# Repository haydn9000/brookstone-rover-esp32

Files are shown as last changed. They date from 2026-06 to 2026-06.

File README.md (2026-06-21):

# Brookstone Rover, ESP32 Conversion

Firmware that converts a Brookstone Rover spy tank (tracked chassis, two DC
motors) into a Bluetooth-gamepad-controlled robot. The original WiFi board is
removed and replaced with an **ESP32 DevKit V1** driving a **DRV8833** dual
H-bridge, with a **BLE gamepad** (PS4 / PS5 / Xbox / generic) as the controller
via [Bluepad32](https://github.com/ricardoquesada/bluepad32). Tested with an
Xbox One Wireless Controller.

The converted rover driving around

## Features

- **BLE gamepad control** through Bluepad32 (no app, pairs directly).
- **Arcade-style mixed drive**, left stick throttles and right stick steers.
- **Hardware PWM** via the ESP32 LEDC peripheral (20 kHz, 8-bit).
- **Deadzone** on the sticks to stop idle jitter.
- **Ramp limiter** for smooth acceleration that protects the gearbox.
- **Slow-decay drive** for more torque and speed per stick input.
- **Failsafe** that stops the motors immediately if the controller disconnects.

## Hardware

| Component | Part | Notes |
|---|---|---|
| MCU | ESP32 DevKit V1 (38-pin, ESP-WROOM-32) | USB micro |
| Motor driver | DRV8833 dual H-bridge breakout | Single-supply (VCC is the motor supply, no separate VM) |
| Power regulation | MP1584EN adjustable buck converter | Set to 5 V output |
| Battery | 6x NiMH AA (7.2 V nominal, ~7.6 V charged) | Rechargeable |
| Chassis | Brookstone Rover tank treads | Two independent tracks (left and right) |

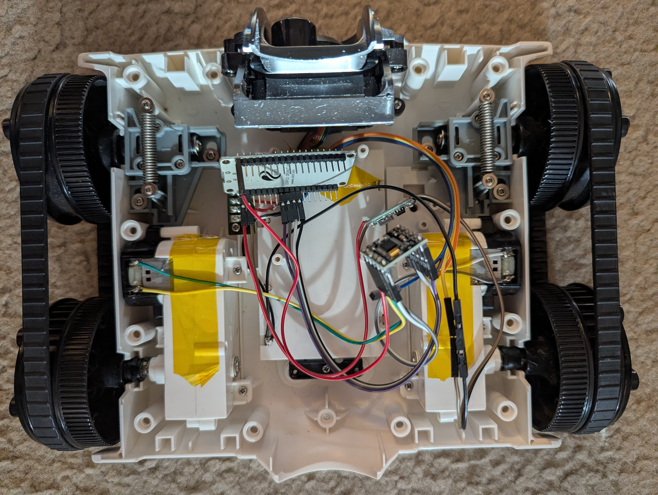
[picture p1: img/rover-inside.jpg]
Inside the rover, ESP32 and DRV8833 wired to the chassis


## Wiring

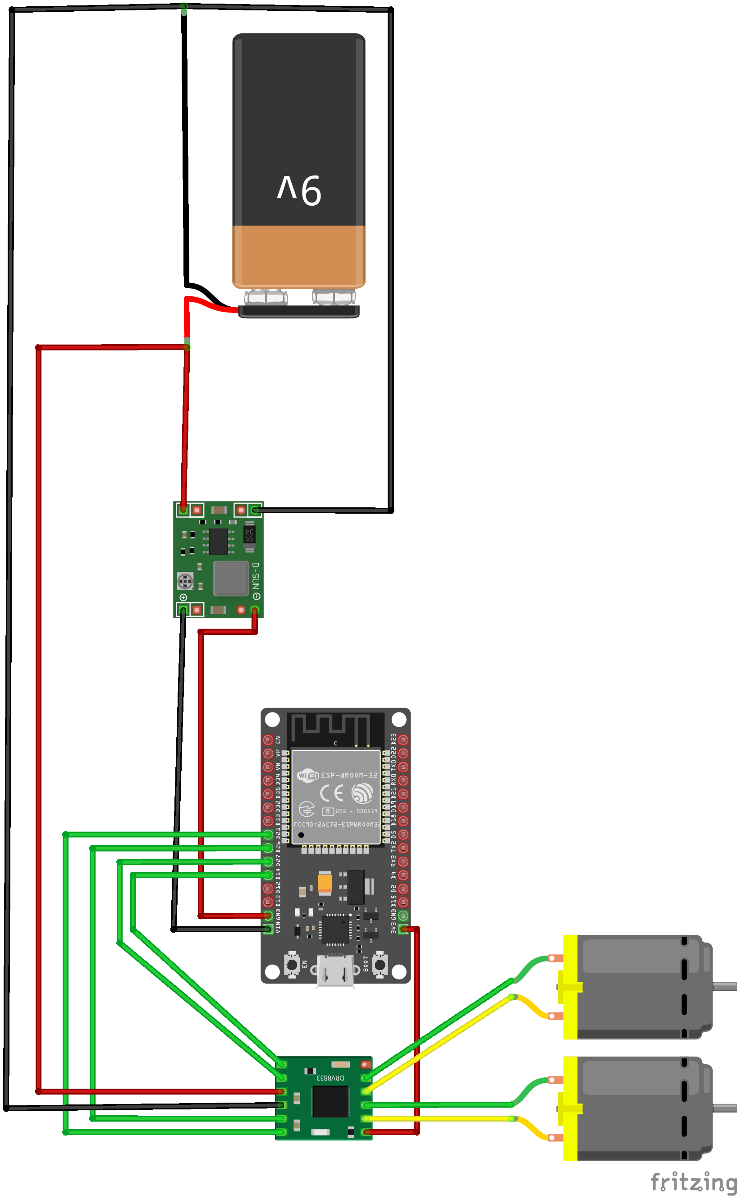
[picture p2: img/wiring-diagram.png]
Fritzing wiring diagram of the ESP32 and DRV8833


### Motor control signals (ESP32 GPIO to DRV8833)

| ESP32 GPIO | DRV8833 | Motor |
|---|---|---|
| GPIO 14 | IN1 | Left, channel A |
| GPIO 27 | IN2 | Left, channel B |
| GPIO 26 | IN3 | Right, channel A |
| GPIO 25 | IN4 | Right, channel B |

- `OUT1`/`OUT2` go to the left motor terminals, `OUT3`/`OUT4` to the right.
- If a track runs backwards, swap its two `OUT` wires (or flip the sign in
  firmware). There is no need to rewire the GPIO.

### Power

- Battery **+** goes through the power switch, then splits to **buck IN+** and
  **DRV8833 VCC** (motor supply, about 7.6 V).
- Buck **OUT+ (5 V)** goes to ESP32 **VIN**, and buck **OUT- (GND)** goes to
  ESP32 **GND**. The ESP32 takes both its 5 V and its ground from the buck
  output, not from the battery directly.
- Battery minus ties to the buck input ground and the DRV8833 GND. Because the
  buck is non-isolated, its input and output grounds are the same node, so
  every ground (battery, buck, ESP32, DRV8833) ends up common.

### Enable pin (important)

This DRV8833 breakout has an **`EEP` / `nSLEEP`** pin that must be driven
**HIGH to enable** the driver. If it is left low (or its onboard pull-up
jumper is open) the chip stays asleep and **the motors will not move even
though everything else is correct**.

- Connect **`EEP` to ESP32 `3V3`**.
- Do **not** tie `EEP` directly to the battery or motor rail. The pin has a
  roughly 6.5 V clamp and is damaged by currents above about 250 µA. Use 3.3 V,
  or a 20 to 75 kΩ resistor to VCC.

## Control scheme

| Input | Action |
|---|---|
| **Left stick, up / down** | Throttle (forward / reverse) |
| **Right stick, left / right** | Steering (turn left / right) |

The two are mixed into the tracks as `left = throttle + steer` and
`right = throttle - steer`. At zero throttle, pushing the steer stick spins the
rover in place.

## Build and flash

This project uses [PlatformIO](https://platformio.org/). With the PlatformIO
CLI on your `PATH`:

```sh
pio run                       # build
pio run --target upload       # flash over USB
pio device monitor            # serial monitor @ 115200 baud
```

> On Windows the bundled CLI may not be on `PATH`. Prefix commands with:
> `$env:PATH += ";$HOME\.platformio\penv\Scripts";`
> Or just use the PlatformIO toolbar and tasks in VS Code.

The board environment is `esp32doit-devkit-v1` (see [platformio.ini](platformio.ini)).

### Bluepad32 note

Bluepad32 needs a Bluetooth-Classic-capable Arduino core, which the stock
ESP32 core does not provide. `platformio.ini` therefore overrides the core
with the precompiled Bluepad32 build via `platform_packages`, so no extra
`lib_deps` entry is required.

## Pairing a controller

Tested with an **Xbox One Wireless Controller** (Bluetooth model). PS4, PS5,
and other Bluepad32-supported gamepads should also work.

1. Flash the firmware and open the serial monitor.
2. Put the gamepad into pairing mode. For an Xbox One controller, turn it on
   with the **Xbox** button, then hold the small **Pair** button on the top
   edge until the Xbox light flashes quickly. (PS4: hold **Share + PS** until
   the light bar flashes.)
3. The ESP32 scans on boot. On success the monitor prints
   `Controller connected, index=0`.
4. To clear stored pairings, uncomment `BP32.forgetBluetoothKeys();` in
   `setup()`, flash once, then comment it back out.

## Tuning

Key constants live near the top of [src/main.cpp](src/main.cpp):

| Constant | Purpose |
|---|---|
| `RAMP_STEP` | Acceleration rate (higher is a snappier launch) |
| `DEADZONE` | Idle stick deadzone (about 10% of axis range) |
| `PWM_FREQ_HZ` | PWM frequency (20 kHz, above the audible range) |

## Known quirks

- **The left track twitches once at power-up.** GPIO 14 emits a brief PWM pulse
  during ESP32 boot, before the firmware takes over. It is harmless. To remove
  it, move `IN1` to a boot-clean GPIO (such as GPIO 13) and update
  `PIN_LEFT_IN1`, or add a 10 kΩ pull-down on GPIO 14.
- **The motors brake when you release the stick.** This is expected with
  slow-decay drive. The disconnect failsafe still coasts.
- The DRV8833 is a small driver (1.2 A continuous, 2 A peak per channel). For
  significantly more speed or torque, use a larger driver such as the TB6612FNG.

## Safety

- Verify the buck converter output is **5 V** with a multimeter before
  connecting the ESP32.
- Never tie the motor or battery rail directly to the ESP32 3.3 V rail or to the
  `EEP` pin.
- Watch the DRV8833 temperature on the first runs. If it gets hot, reduce the
  load or `RAMP_STEP`.

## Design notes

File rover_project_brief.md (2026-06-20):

# Brookstone Rover ESP32 Conversion — Claude Code Brief

## Project Summary
Converting a Brookstone Rover spy tank (tracked chassis with 2 DC motors)
into a BLE-gamepad-controlled robot using an ESP32, replacing the original
WiFi control board entirely.

## Hardware

| Component | Part | Notes |
|---|---|---|
| MCU | ESP32 DevKit V1 (38-pin, ESP-WROOM-32 module) | USB micro |
| Motor driver | DRV8833 dual H-bridge module | WWZMDiB breakout board |
| Power regulation | MP1584EN adjustable buck converter | Set to 5V output |
| Battery | 6x NiMH AA (7.2V nominal) | Rechargeable |
| Power switch | Toggle switch | On battery + line, before split |
| Chassis | Brookstone Rover tank treads | 2 independent tracks, left + right |

## Confirmed Pin Wiring (from physical board photo)

**Power:**
- Battery + → switch → splits to: MP1584 IN+ AND DRV8833 VM
- Battery − → common GND bus
- MP1584 OUT+ (5V) → ESP32 VIN
- MP1584 OUT− → common GND bus
- ESP32 3V3 → DRV8833 VCC (logic power)
- Common GND bus ties together: battery −, MP1584 GND, ESP32 GND, DRV8833 GND

**Motor control signals (ESP32 GPIO → DRV8833):**
- GPIO 14 → DRV8833 IN1 (left motor, channel A)
- GPIO 27 → DRV8833 IN2 (left motor, channel B)
- GPIO 26 → DRV8833 IN3 (right motor, channel A)
- GPIO 25 → DRV8833 IN4 (right motor, channel B)

**DRV8833 motor outputs:**
- OUT1/OUT2 → left motor terminals
- OUT3/OUT4 → right motor terminals
- (If a motor spins the wrong direction, swap its two OUT wires — no code change needed)

**GPIO pins confirmed AVOID on this board:**
- GPIO 12 (boot failure risk if HIGH at startup)
- GPIO 1/3 (TX0/RX0 — used by USB serial)

## Motor Control Logic (DRV8833)

| IN_a | IN_b | Result |
|---|---|---|
| PWM | LOW | Forward, speed = duty cycle |
| LOW | PWM | Reverse, speed = duty cycle |
| LOW | LOW | Coast (free spin) |
| HIGH | HIGH | Brake |

## Software Requirements

1. **Framework**: PlatformIO (preferred environment), Arduino framework for ESP32
2. **BLE gamepad support**: Use the **Bluepad32** library — supports PS4, PS5, Xbox, and generic BLE gamepads with robust pairing/reconnection handling
3. **Control scheme**:
   - Left analog stick Y-axis → left track speed/direction
   - Right analog stick Y-axis → right track speed/direction
   - (Tank-style differential drive control)
4. **PWM**: Use ESP32 `ledcWrite()` / LEDC peripheral for smooth speed control on all 4 GPIO pins (avoid `analogWrite` — not native on ESP32 in all cores)
5. **Safety features to include**:
   - Deadzone handling on analog stick input to prevent motor jitter at rest
   - Failsafe: if BLE controller disconnects, stop both motors immediately
   - Optional: gentle ramp-up/ramp-down rather than instant full power, to protect the gearbox

## What to ask Claude Code to do

Use the prompt below as your starting message to Claude Code.

---

### PROMPT FOR CLAUDE CODE

```
I'm building a tank-drive robot using an ESP32 DevKit V1 and a DRV8833 motor
driver, controlled by a BLE gamepad. Please set up a PlatformIO project for this.

Hardware:
- ESP32 DevKit V1 (38-pin, ESP-WROOM-32 module)
- DRV8833 dual H-bridge motor driver
- Two DC motors (left track, right track)
- Powered by 6x NiMH AA batteries (7.2V) through a buck converter to 5V for the ESP32

Pin wiring:
- GPIO 14 -> DRV8833 IN1 (left motor, channel A)
- GPIO 27 -> DRV8833 IN2 (left motor, channel B)
- GPIO 26 -> DRV8833 IN3 (right motor, channel A)
- GPIO 25 -> DRV8833 IN4 (right motor, channel B)

Requirements:
1. Use the Bluepad32 library for BLE gamepad support (PS4/PS5/Xbox/generic controllers)
2. Use ESP32 LEDC PWM (ledcWrite) for motor speed control, not analogWrite
3. Tank-style differential drive: left stick Y-axis controls left track,
   right stick Y-axis controls right track
4. Add a deadzone (~10%) on stick input to prevent motor jitter when centered
5. If the gamepad disconnects, immediately stop both motors (failsafe)
6. Add a basic ramp limiter so motor speed changes smoothly rather than
   snapping instantly to full power/reverse, to protect the gearbox
7. Set up platformio.ini with the correct board (esp32dev — this matches the
   ESP32 DevKit V1), framework (arduino), and add Bluepad32 as a lib dependency

Please create the full project structure, write the main.cpp with clear
comments, and explain how to flash it to the board over USB.
```

---

## Notes for You

- Before flashing, **double-check the MP1584 is set to 5V** with a multimeter — this is a one-time setup step, not part of the firmware
- The DRV8833 should already be wired per the diagrams we made earlier
- If a track runs backwards once you test it, you can fix it in software (swap which GPIO is "forward") instead of re-wiring, which is often easier
- Bluepad32 has its own PlatformIO library registry entry — Claude Code should be able to add it directly via `lib_deps`

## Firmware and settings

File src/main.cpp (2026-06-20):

// =============================================================================
//  Brookstone Rover — ESP32 arcade-drive firmware
// -----------------------------------------------------------------------------
//  Hardware:
//    - ESP32 DevKit V1 (38-pin, ESP-WROOM-32)
//    - DRV8833 dual H-bridge motor driver
//    - Two DC motors (left track, right track)
//
//  Control:
//    - BLE gamepad via Bluepad32 (PS4 / PS5 / Xbox / generic)
//    - Arcade-style mixed drive:
//        * Left  stick Y-axis  -> throttle (forward / reverse)
//        * Right stick X-axis  -> steering (turn left / right)
//      Mixed to tracks: left = throttle + steer, right = throttle - steer.
//
//  Pin wiring (ESP32 GPIO -> DRV8833):
//    - GPIO 14 -> IN1 (left  motor, channel A)  [emits a brief PWM pulse at
//                  boot, so the left track may twitch once on power-up]
//    - GPIO 27 -> IN2 (left  motor, channel B)
//    - GPIO 26 -> IN3 (right motor, channel A)
//    - GPIO 25 -> IN4 (right motor, channel B)
//
//  DRV8833 in-in (PWM) control logic per motor (slow decay / drive-brake):
//    INa=HIGH, INb=PWM   -> forward (lower INb duty = faster)
//    INa=PWM,  INb=HIGH  -> reverse
//    INa=HIGH, INb=HIGH  -> brake
//    INa=LOW,  INb=LOW   -> coast (failsafe stop)
// =============================================================================

#include <Arduino.h>
#include <Bluepad32.h>

// -----------------------------------------------------------------------------
// Pin assignments
// -----------------------------------------------------------------------------
static const int PIN_LEFT_IN1  = 14;  // left  motor, channel A
static const int PIN_LEFT_IN2  = 27;  // left  motor, channel B
static const int PIN_RIGHT_IN3 = 26;  // right motor, channel A
static const int PIN_RIGHT_IN4 = 25;  // right motor, channel B

// -----------------------------------------------------------------------------
// LEDC (hardware PWM) configuration
//   Arduino-ESP32 core 2.x style API: ledcSetup() / ledcAttachPin() / ledcWrite()
//   One LEDC channel per H-bridge input (4 total).
// -----------------------------------------------------------------------------
static const int LEDC_CH_LEFT_IN1  = 0;
static const int LEDC_CH_LEFT_IN2  = 1;
static const int LEDC_CH_RIGHT_IN3 = 2;
static const int LEDC_CH_RIGHT_IN4 = 3;

static const int   PWM_FREQ_HZ   = 20000;  // 20 kHz: above audible range, smooth
static const int   PWM_RES_BITS  = 8;      // 8-bit resolution -> duty 0..255
static const int   PWM_MAX       = 255;    // max duty for PWM_RES_BITS

// -----------------------------------------------------------------------------
// Control tuning
// -----------------------------------------------------------------------------
// Bluepad32 analog axes report roughly -512..511. Up on the stick is negative,
// so we invert to make "stick up = forward".
static const int   AXIS_MAX      = 512;

// Deadzone (~10%) so a centered/idle stick produces zero output (no jitter).
static const int   DEADZONE      = (AXIS_MAX * 10) / 100;  // ~51

// Ramp limiter: maximum change in motor command per control update. Smaller =
// gentler acceleration/deceleration, which protects the gearbox.
static const int   RAMP_STEP     = 30;     // duty units per ~10 ms update

// Control loop period.
static const unsigned long CONTROL_PERIOD_MS = 10;

// -----------------------------------------------------------------------------
// State
// -----------------------------------------------------------------------------
ControllerPtr myControllers[BP32_MAX_GAMEPADS];

// Current (ramped) and target motor commands, range -PWM_MAX..PWM_MAX.
static int leftCurrent  = 0;
static int rightCurrent = 0;
static int leftTarget   = 0;
static int rightTarget  = 0;

static unsigned long lastControlMs = 0;

// -----------------------------------------------------------------------------
// Low-level motor driver
// -----------------------------------------------------------------------------
// Drive one motor. `speed` in -PWM_MAX..PWM_MAX (sign = direction, 0 = coast).
//
// Slow-decay ("drive/brake") PWM: hold one input HIGH and PWM the other with the
// INVERTED duty. Per the DRV8833 truth table this keeps the winding energized
// during the PWM-off interval, delivering more effective voltage/torque per duty
// than fast decay -> more top speed and pep. Trade-offs: motors run a little
// warmer and brake harder when the stick is released.
static void driveMotor(int chA, int chB, int speed) {
  speed = constrain(speed, -PWM_MAX, PWM_MAX);
  if (speed >= 0) {
    ledcWrite(chA, PWM_MAX);          // forward, slow decay
    ledcWrite(chB, PWM_MAX - speed);  // inverted duty on the other input
  } else {
    ledcWrite(chA, PWM_MAX - (-speed));
    ledcWrite(chB, PWM_MAX);          // reverse, slow decay
  }
}

// Immediately stop both motors (coast). Used by the failsafe.
static void stopMotors() {
  leftTarget = rightTarget = 0;
  leftCurrent = rightCurrent = 0;
  ledcWrite(LEDC_CH_LEFT_IN1, 0);
  ledcWrite(LEDC_CH_LEFT_IN2, 0);
  ledcWrite(LEDC_CH_RIGHT_IN3, 0);
  ledcWrite(LEDC_CH_RIGHT_IN4, 0);
}

// Convert a raw stick axis (-AXIS_MAX..AXIS_MAX, up = negative) into a motor
// command (-PWM_MAX..PWM_MAX, positive = forward) with deadzone handling.
static int axisToSpeed(int axis) {
  if (abs(axis) < DEADZONE) {
    return 0;
  }
  // Invert so pushing the stick up drives the track forward.
  int command = map(-axis, -AXIS_MAX, AXIS_MAX, -PWM_MAX, PWM_MAX);
  return constrain(command, -PWM_MAX, PWM_MAX);
}

// Convert a raw stick axis (-AXIS_MAX..AXIS_MAX) into a steering command
// (-PWM_MAX..PWM_MAX, positive = turn right) with deadzone handling. Unlike
// axisToSpeed() this is NOT inverted: pushing the stick right is positive.
static int axisToSteer(int axis) {
  if (abs(axis) < DEADZONE) {
    return 0;
  }
  int command = map(axis, -AXIS_MAX, AXIS_MAX, -PWM_MAX, PWM_MAX);
  return constrain(command, -PWM_MAX, PWM_MAX);
}

// Move `current` toward `target` by at most RAMP_STEP.
static int rampToward(int current, int target) {
  if (current < target) {
    return min(current + RAMP_STEP, target);
  } else if (current > target) {
    return max(current - RAMP_STEP, target);
  }
  return current;
}

// -----------------------------------------------------------------------------
// Bluepad32 connection callbacks
// -----------------------------------------------------------------------------
static void onConnectedController(ControllerPtr ctl) {
  for (int i = 0; i < BP32_MAX_GAMEPADS; i++) {
    if (myControllers[i] == nullptr) {
      Serial.printf("Controller connected, index=%d\n", i);
      myControllers[i] = ctl;
      return;
    }
  }
  Serial.println("Controller connected, but no empty slot found");
}

static void onDisconnectedController(ControllerPtr ctl) {
  for (int i = 0; i < BP32_MAX_GAMEPADS; i++) {
    if (myControllers[i] == ctl) {
      Serial.printf("Controller disconnected, index=%d\n", i);
      myControllers[i] = nullptr;
      break;
    }
  }
  // Failsafe: if no controllers remain connected, stop immediately.
  bool anyConnected = false;
  for (int i = 0; i < BP32_MAX_GAMEPADS; i++) {
    if (myControllers[i] != nullptr) {
      anyConnected = true;
      break;
    }
  }
  if (!anyConnected) {
    stopMotors();
    Serial.println("No controllers connected -> motors stopped (failsafe)");
  }
}

// -----------------------------------------------------------------------------
// Read the first connected gamepad and update motor targets.
// -----------------------------------------------------------------------------
static void updateTargetsFromGamepad() {
  ControllerPtr gamepad = nullptr;
  for (int i = 0; i < BP32_MAX_GAMEPADS; i++) {
    if (myControllers[i] && myControllers[i]->isConnected() &&
        myControllers[i]->isGamepad()) {
      gamepad = myControllers[i];
      break;
    }
  }

  if (gamepad == nullptr) {
    // No usable gamepad -> coast to a stop via the ramp limiter.
    leftTarget = 0;
    rightTarget = 0;
    return;
  }

  // Arcade mixing: left stick Y = throttle (forward/back), right stick X =
  // steering (turn left/right). Combine into per-track commands so one stick
  // drives and the other turns; pushing steer at zero throttle spins in place.
  int throttle = axisToSpeed(gamepad->axisY());   // left  stick Y, up = forward
  int steer    = axisToSteer(gamepad->axisRX());  // right stick X, right = right

  leftTarget  = constrain(throttle + steer, -PWM_MAX, PWM_MAX);
  rightTarget = constrain(throttle - steer, -PWM_MAX, PWM_MAX);
}

// -----------------------------------------------------------------------------
// Arduino entry points
// -----------------------------------------------------------------------------
void setup() {
  Serial.begin(115200);

  // Configure LEDC PWM channels and bind them to the H-bridge input pins.
  ledcSetup(LEDC_CH_LEFT_IN1,  PWM_FREQ_HZ, PWM_RES_BITS);
  ledcSetup(LEDC_CH_LEFT_IN2,  PWM_FREQ_HZ, PWM_RES_BITS);
  ledcSetup(LEDC_CH_RIGHT_IN3, PWM_FREQ_HZ, PWM_RES_BITS);
  ledcSetup(LEDC_CH_RIGHT_IN4, PWM_FREQ_HZ, PWM_RES_BITS);

  ledcAttachPin(PIN_LEFT_IN1,  LEDC_CH_LEFT_IN1);
  ledcAttachPin(PIN_LEFT_IN2,  LEDC_CH_LEFT_IN2);
  ledcAttachPin(PIN_RIGHT_IN3, LEDC_CH_RIGHT_IN3);
  ledcAttachPin(PIN_RIGHT_IN4, LEDC_CH_RIGHT_IN4);

  stopMotors();  // start safely stopped

  // Initialize Bluepad32.
  const uint8_t* addr = BP32.localBdAddress();
  Serial.printf("Bluepad32 firmware: %s\n", BP32.firmwareVersion());
  Serial.printf("BD Addr: %02X:%02X:%02X:%02X:%02X:%02X\n",
                addr[0], addr[1], addr[2], addr[3], addr[4], addr[5]);

  BP32.setup(&onConnectedController, &onDisconnectedController);

  // Mice / keyboards are not used; keep only gamepads.
  BP32.enableVirtualDevice(false);

  // Uncomment once to clear stored pairings if a controller won't reconnect:
  // BP32.forgetBluetoothKeys();
}

void loop() {
  // Poll Bluepad32. Returns true when fresh controller data is available.
  bool dataUpdated = BP32.update();
  if (dataUpdated) {
    updateTargetsFromGamepad();
  }

  // Run the ramp limiter + motor output on a fixed cadence.
  unsigned long now = millis();
  if (now - lastControlMs >= CONTROL_PERIOD_MS) {
    lastControlMs = now;

    leftCurrent  = rampToward(leftCurrent,  leftTarget);
    rightCurrent = rampToward(rightCurrent, rightTarget);

    driveMotor(LEDC_CH_LEFT_IN1,  LEDC_CH_LEFT_IN2,  leftCurrent);
    driveMotor(LEDC_CH_RIGHT_IN3, LEDC_CH_RIGHT_IN4, rightCurrent);
  }

  // Throttled status print to diagnose connection / drive problems.
  static unsigned long lastDebugMs = 0;
  if (now - lastDebugMs >= 500) {
    lastDebugMs = now;
    ControllerPtr gp = nullptr;
    for (int i = 0; i < BP32_MAX_GAMEPADS; i++) {
      if (myControllers[i] && myControllers[i]->isConnected()) {
        gp = myControllers[i];
        break;
      }
    }
    if (gp == nullptr) {
      Serial.println("[status] no controller connected (scanning for pairing)...");
    } else {
      Serial.printf(
        "[status] axisX=%d axisY=%d axisRX=%d axisRY=%d brake=%d throttle=%d buttons=%d dpad=%d  L=%d R=%d\n",
        gp->axisX(), gp->axisY(), gp->axisRX(), gp->axisRY(),
        gp->brake(), gp->throttle(), gp->buttons(), gp->dpad(),
        leftCurrent, rightCurrent
      );
    }
  }

  // Yield to the Bluetooth stack.
  delay(1);
}
